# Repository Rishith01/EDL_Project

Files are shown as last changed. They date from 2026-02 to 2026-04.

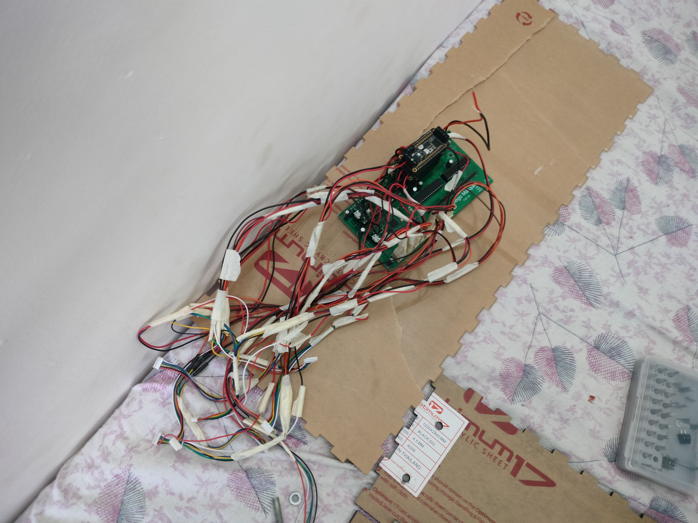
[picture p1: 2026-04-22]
others/extras/images/PCB_wiring.jpg

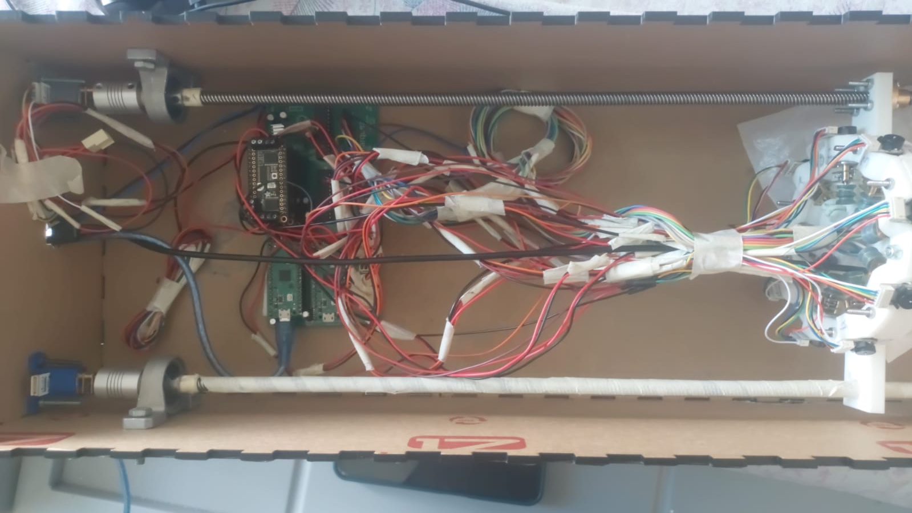
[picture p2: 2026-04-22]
others/images/wiring.jpeg

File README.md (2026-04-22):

<!-- Do Not Change the below line. It will affect your workflow badge -->
Review Assignment Due Date (https://classroom.github.com/a/9lqHKop1)



<!-- ADD YOUR CHANGES AFTER THIS LINE -->

# SACE(Secure Adaptive Continuum Explorer)
**Team TUE-16 | Indian Institute of Technology Bombay**

---

## Team Members
* **Arijit Paul** (23B1219)
* **Arshit Singh** (23B1275)
* **Prithvi Sangam** (23B1292)
* **Rishith Gupta** (23B1234)
* **Veeresh S K** (23B1309)

---

## Project Abstract
This project investigates the practical implementation of **soft robotics** through the development of a modular, tentacle-based end effector on a continuum backbone. The system is engineered to navigate highly constrained environments and perform adaptive grasping of irregular objects. 

The architecture consists of a **continuum robotic arm featuring four flexible segments** capable of extending from a compact enclosure. By integrating 10 degrees of freedom (DOF), tendon-driven actuation, and real-time visual feedback, the robot demonstrates the capability of compliant structures to achieve dexterity and safety in applications where traditional rigid-link manipulators are insufficient.

---

## Key Technical Features
* **Deployable Mechanism:** Engineered for high spatial efficiency, allowing the arm to extend from a compact housing for maximum reach-to-storage ratio.
* **Continuum Kinematics:** A multi-link flexible structure that facilitates smooth, non-discrete bending for complex maneuvering in tight spaces.
* **Adaptive Morphology:** The tentacle-inspired design conforms naturally to the geometry of target objects, ensuring secure grasping through compliant contact.
* **Teleoperated Control:** Real-time operation via a gaming controller/click based interface, mapping user input directly to multi-segment motion.
* **Integrated Vision System:** An endoscope camera provides a live stream to the operator for precise navigation and targeting.
* **Active Safety Array:** Integrated limit switches detect external obstacles and mechanical limits to prevent system damage and ensure safe motion.
* **Modularity:** The system is partitioned into independent subsystems, allowing for streamlined repair, scaling, and iterative refinement.

---

## System Overview

### Hardware Architecture
* **Controller Architecture:** Dual Raspberry Pi Pico microcontrollers configured in a Master–Slave hierarchy to distribute real-time processing loads.
* **Motor Control:** Three Adafruit FeatherWing Motor Drivers, selected for their high-density power management and compact footprint.
* **Actuation:** 11 N20 micro-gear motors dedicated to tendon-driven link manipulation through specialized differential spools.
* **Sensing Array:** 16 Limit Switches (distributed as 4 per continuum segment) for obstacle detection and motion constraint.
* **Vision:** A high-resolution endoscope camera module for front-facing orientation and feedback with 60 degree field of view.
* **Electronics:** A custom-designed PCB for efficient power distribution and signal routing, including 12V to 3.3V power conversion.

### Software Architecture
* **Workstation Logic:** Python-based control scripts on the laptop for signal processing, controller mapping, and user interface management.
* **Embedded Firmware:** MicroPython-based scripts running on the Raspberry Pi Pico for low-level hardware control and motor actuation.
* **Visual Pipeline:** Python-based live feed processing for real-time operator guidance.
The flowcharts and execution logic are present in the folder READMEs. Refer to particular folder for more details.
---

## Working Principle
1.  **Input Acquisition:** The operator provides motion commands through a gaming controller/click and keyboard interface.
2.  **Signal Processing:** The laptop-based Python environment translates given commands into specific link-actuation commands and calculates which link is to move how much using our control algorithm.
3.  **Command Dispatch:** Control signals are transmitted to the Master Raspberry Pi Pico.
4.  **Distributed Execution:** The Master Pico coordinates with the Slave Pico and the motor driver array to execute precise motor rotations.
5.  **Actuation:** N20 motors rotate the differential spools, pulling tendons to induce controlled bending in the continuum segments.
6.  **Feedback Loop:** Real-time visual data from the camera and tactile data from the limit switches are monitored to guide navigation and prevent collisions.

---

## Final Deliverables

The project delivers a fully functional soft robotic system with the following capabilities:

- **Continuum Robotic Arm System**
  - A four-segment tendon-driven continuum arm capable of smooth, multi-directional bending  
  - Designed to navigate constrained environments with high flexibility  

- **Tentacle-Based End Effector**
  - A compliant gripper capable of adaptive grasping of irregular objects  
  - Independently actuated for controlled gripping  

- **Teleoperation Interface**
  - Real-time control using keyboard, mouse, and gaming controller  
  - Supports intuitive interaction through a camera-based interface  

- **Vision-Guided Operation**
  - Integrated endoscope camera providing live visual feedback  
  - Enables precise navigation and targeting  

- **Safety Mechanism**
  - Limit switch array for obstacle detection and motion constraint  
  - Automatic escape responses to prevent system damage  

- **Custom Embedded Control System**
  - Dual Raspberry Pi Pico architecture (Master–Slave)  
  - Distributed control for motor actuation and hardware interfacing  

- **Mechanical and Electronic Integration**
  - Fully assembled system including:
    - Custom PCB  
    - Motor driver integration  
    - Tendon-driven actuation system  

- **User Interface and Control Software**
  - Python-based host system for trajectory planning and control  
  - MicroPython firmware for real-time embedded execution  

---

## Repository Structure

```plaintext
├── src/                # Source code (MicroPython + Python)
├── pcb/                # PCB designs and schematics
│   └── PCB1/
│       ├── design.brd
│       ├── schematic.src
│       └── pictures/   # Fabricated PCB and Fusion 360 layouts
├── 3d_models/          # CAD models (Fusion 360)
│   ├── tentacle/
│   ├── continuum/
│   ├── base_plate/
|   ├── enclosure/
│   ├── spool/
|   └── motor_mount/
├── reports/            # Project Milestone Documentation
│   ├── milestone0/
│   ├── milestone1/
│   ├── milestone2/
|   ├── milestone3/
│   └── milestone4/
├── others/
│   ├── user_manual/    # Operational instructions
│   ├── presentation/   # System demonstration
|       ├── slides/
│       └── video/    
|   ├── images/         # Images of final setup
|   ├── extras/         # Extra images and videos
|   └── diagrams/       # Relevant diagrams
├── bom.xls             # Detailed Bill of Materials
└── README.md
```

## Repository Walkthrough

### src/
Contains all source code for the system, including:
- MicroPython code for the Raspberry Pi Pico, master and slave RPi (motor control, hardware interfacing)
- Python-based host code for user interaction, trajectory planning, and communication  

Each subfolder is organized based on the execution platform and includes relevant README files describing usage and setup.

---

### pcb/
Includes all PCB-related design files and documentation:
- Schematic and layout files for the custom PCB  
- Fabrication outputs and board design files  
- Images of the fabricated PCB and assembled boards  

The PCB integrates motor drivers, power distribution, and control interfaces required for system operation.

---

### 3d_models/
Contains all mechanical CAD designs used in the project.  
The models are organized into subsystem-level folders:
- **tentacle and top_link/** – End-effector for gripping and top link continuum link
- **continuum/** – Flexible links enabling motion  
- **base_plate/** – Structural base and motor mounting  
- **enclosure/** – Outer housing (laser-cut design)  
- **spools/** – Tendon winding mechanisms  
- **Motor Mount/** – Motor holding structures  

Each folder includes design files, images, and descriptions of functionality and assembly.

---

### reports/
Contains all milestone reports documenting the project lifecycle:
- Concept development  
- Design iterations  
- Implementation progress  
- Final system evaluation  

All reports are provided in PDF format.

---

### others/
Contains supporting materials required for understanding and operating the system:
- **user_manual/** – Step-by-step instructions for setup and operation  
- **presentation/** – Slides and demonstration video  
- **images/** – Photographs of the final assembled system  
- **diagrams/** – Wiring diagrams and system-level representations
- **extras/** - Extra images and videos during testing and prototyping

---

### bom.xls
A detailed Bill of Materials listing all components used in the project, including:
- Electronic components  
- Mechanical parts  
- Consumables and fabrication materials  

Each entry includes quantity, description, and source information.

---

### README.md
The root documentation file providing:
- Project overview and objectives  
- System description  
- Repository structure  
- Key features and functionality  
---

## Technical Constraints and Operational Limits
The current design represents a balance between mechanical performance and the physical limitations of the materials and space.

1. **Bending Threshold**: Empirical testing established a stable operational limit of approximately 30° per link. Beyond this angle, mechanical stress increases significantly, contributing to tendon slack issues within the actuation system.

2. **Control Paradigm**: Currently restricted to manual teleoperation; autonomous path planning and inverse kinematics are not yet implemented.

3. **Backbone Hysteresis and Droop**: The use of glue gun sticks as a central backbone introduces stability issues. After bending, the backbone may fail to return to a perfectly linear state, causing the robot to droop. Ensuring the backbone is fixed at the start and end of each link segment is critical for maintaining a consistent neutral axis.

4. **Tendon Dynamics**: Issues regarding tendon slack and potential thread interference in the shared spool design persist during extreme ranges of motion.

---

## Course Reflection and Learnings

### Technical Learnings

This project provided hands-on experience across multiple domains:

- **Mechanical Design**
  - Designing for tolerances and iterative prototyping  
  - Understanding trade-offs between flexibility and structural strength  
  - Challenges in tendon-driven systems such as slack and routing  

- **Embedded Systems**
  - Working with dual microcontroller architecture (Master–Slave)  
  - Interfacing peripherals such as motor drivers, encoders, and port expanders  
  - Handling real-time constraints in MicroPython  

- **Control Systems**
  - Implementing coordinated multi-link motion  
  - Understanding limitations of open-loop control  
  - Practical challenges in achieving smooth motion  

- **PCB Design**
  - Designing and debugging custom PCBs  
  - Managing power distribution and signal routing  
  - Handling hardware failures and component sensitivity  

- **System Integration**
  - Combining mechanical, electrical, and software subsystems  
  - Debugging issues arising only during full system integration  

---

### Team Challenges and Adaptation

- **Subsystem Isolation and Testing**
  - Each subsystem (mechanical, electronics, software) was tested independently before integration  
  - This helped in identifying issues early and reducing debugging complexity  

- **Iterative Prototyping**
  - Multiple iterations were required, especially for:
    - Spool design  
    - Tentacle structure  
    - Continuum links  
  - Rapid prototyping enabled quick validation and refinement  

- **Cross-Domain Collaboration**
  - Team members developed working knowledge of other subsystems  
  - Ensured continuity when specific members were unavailable  

- **Integration Challenges**
  - Most issues arose during integration rather than individual subsystem development  
  - Required coordinated debugging sessions and time alignment among team members  

---

### Honest Reflection

- While the final system achieves the intended functionality, a significant portion of the effort was spent resolving **practical engineering challenges** rather than implementing advanced features  

- Mechanical reliability (tolerances, tendon routing, slack management) proved to be more critical and time-consuming than initially anticipated  

- Hardware failures (motor drivers, microcontrollers) highlighted the importance of robust electrical design and protection  

- The control system works effectively for manual operation, but lacks higher-level intelligence and automation  

- Overall, the project demonstrates a **working proof-of-concept**, but not a fully optimized or production-ready system  

---

### Incomplete Features and Limitations

The following aspects remain incomplete:

- **Autonomous Control**
  - No implementation of inverse kinematics or automated path planning  
  - Reason: Complexity of modeling continuum kinematics and time constraints  

- **Closed-Loop Feedback**
  - Limited use of encoder data for precise control  
  - Reason: Integration complexity and prioritization of basic functionality  

- **Robust Tendon Management**
  - Issues with slack, overlap, and spool behavior at extreme motions  
  - Reason: Mechanical design constraints and limited iteration time  

- **System Stability**
  - Vibrations and minor inaccuracies in motion  
  - Reason: Structural limitations and compact design constraints  

---

### Future Work 

- **Inverse Kinematics for Continuum Arms**
  - Develop simplified models for controlled positioning  

- **Improved Tendon Mechanism**
  - Dedicated spool designs with better separation and tension control  

- **Enhanced Feedback Control**
  - Utilize encoder data for closed-loop control  
  - Implement PID-based corrections  

- **Structural Improvements**
  - Replace glue stick backbone with engineered compliant structures  

- **Miniaturization**
  - Redesign base plate and enclosure for reduced footprint  

- **System Robustness**
  - Add electrical protection (snubbers, proper grounding, shielding)  

---

## Acknowledgements
We extend our sincere gratitude to Prof. Siddharth Tallur, Prof. Himanshu Bahirat, and Prof. P. C. Pandey for their continuous guidance and valuable insights throughout this project. We also acknowledge the support of Ankur, Maheshwar, the WEL RAs and TAs for their technical assistance during the development and debugging phases.

## Inspiration 
The inspiration for the tentacle end effector came from this youtube video of the spirobs bot: https://m.youtube.com/watch?v=Q2yYclPaEV0

Inspiration for the continuum arm came from this video from continnum robotics lab of university of toronto. https://m.youtube.com/watch?v=MxBeUQay8YM

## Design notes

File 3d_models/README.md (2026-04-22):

#  3D Models Overview

This directory contains all mechanical design files used in the Tentacle Arm End Effector project. The designs follow a **modular architecture**, enabling independent development, testing, and iteration of each subsystem.

---

##  Design Philosophy
- **Modularity** – Each subsystem (tentacle, continuum links, base, etc.) is designed independently for ease of iteration and replacement  
- **Tendon-driven actuation** – Motion is achieved through routed tendons enabling flexible bending  
- **Iterative prototyping** – Multiple versions were developed to resolve tolerance, routing, and mechanical constraints  
- **Ease of fabrication** – Designs are optimized for rapid prototyping using accessible manufacturing methods  

---

##  Manufacturing Methods
- **3D Printing ** – Used for all structural components (STL files)
- **Laser Cutting** – Used for enclosure panels (DXF files)  

---

##  Materials Used
- **PLA (Primary Material)**  
  - Chosen for its balance between rigidity, printability, and cost  
  - Provides sufficient structural strength while allowing minor compliance  

- **TPU (Tested)**  
  - Too flexible for structural components  

- **Resin (Tested)**  
  - High precision but expensive and limited in build volume  

- **Acrylic (6mm)**  
  - Used for enclosure panels via laser cutting  

---

##  Design Considerations
- **Tolerance management** was critical across all components  
- Minor post-processing (filing/drilling) was required in tight-fit regions  
- **Tendon routing** and **vinyl tubing guidance** were key constraints  
- Structural strength balanced with flexibility for continuum motion  

---

##  System Integration
The mechanical assembly follows this structure:
entacle → Continuum Links (×4) → Base Plate → Lead Screw → Enclosure

- The **tentacle** performs grasping  
- The **continuum links** enable flexible motion  
- The **base plate** houses motors and routing  
- The **lead screw** enables linear extension  
- The **enclosure** houses the entire system  

---

## Folder Structure
```plaintext
.
├── enclosure/     # Laser-cut enclosure designs (DXF)
├── base_plate/    # Base plate designs and iterations
├── spools/        # Tendon winding mechanisms
├── continuum/     # Continuum link structures
└── tentacle/      # Gripper/tentacle designs
```

Each folder contains design files along with images and detailed README documentation.

## Assembly Instructions

The assembly of the Tentacle Arm End Effector is carried out in stages, starting from the continuum structure to the final enclosure integration.

---

### 1. Continuum Link Assembly

- Attach the continuum link segments along a central **hot glue stick backbone**, maintaining uniform spacing  
- For each link:
  - Tie **four fishing lines** at 90° intervals around the link  
  - Ensure consistent positioning for symmetric actuation  

---

### 2. Tendon Routing

- Route each fishing line through the **vinyl tubing guides**  
- This ensures:
  - Reduced friction  
  - Controlled motion  
  - Proper alignment between links  

- Repeat this process for all continuum links and route all tendons down to the base plate  

---

### 3. Base Plate and Motor Assembly

- Mount all motors securely onto the **base plate** using appropriate screws  
- Route the fishing lines through designated holes in the base plate  
- Wind each tendon onto its respective **spool mechanism**  
- Attach the spools firmly onto the **motor D-shafts**

---

### 4. Lead Screw Integration

- Connect the **base plate** to the lead screw mechanism  
- Attach the lead screw to the motor using a **shaft coupler**  
- Mount the lead screw motor onto the **motor mount**

---

### 5. Enclosure Integration

- Fix the motor mount and lead screw assembly inside the **enclosure**  
- Ensure alignment of the continuum structure with the enclosure exit opening  

- For additional stability:
  - Support the lead screw using **pillow bearings**  
  - Secure them to the enclosure structure  

---

### 6. Final Checks

- Verify all tendons are properly tensioned  
- Ensure smooth rotation of motors and spools  
- Check for:
  - No tendon overlap  
  - No obstruction in tubing  
  - Free movement of continuum links 
- Can check for each motor's working and mechanical issues by running individual commands on Thonny for each motor. 

---

### Notes

- Minor adjustments (tightening, re-routing, or trimming) may be required due to tolerance variations  
- Proper tendon tension is critical for accurate motion and control

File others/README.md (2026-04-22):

# Others Directory

This directory contains all supplementary materials related to the **SACE (Secure Adaptive Continuum Explorer)** project. It complements the core implementation by providing user documentation, system visuals, demonstrations, and additional validation data.

---

## Purpose

The `/others` folder is intended to:
- Provide a complete **user-facing understanding** of the system  
- Document the **final assembled setup** visually  
- Showcase **demonstration and testing results**  
- Include **supporting diagrams and development artifacts**  

---

## Folder Structure

```plaintext
others/
├── user_manual/
├── presentation/
│   ├── slides/
│   └── video/
├── images/
├── diagrams/
└── extras/
```

## Subfolder Descriptions
🔹 user_manual/

This folder contains the User Manual for the SACE system.

It includes:
```
System setup instructions
Step-by-step operating procedures
Safety guidelines
Troubleshooting information
```
This document is intended for end-users interacting with the system.

🔹 presentation/

This folder contains materials used for project demonstration and evaluation.
```
slides/: Final presentation slides (PDF format)
video/: Demonstration videos showcasing system operation, capabilities, and performance
```
🔹 images/

This folder contains images of the final assembled system, including:
```
Overall system setup
Mechanical structure
Electronics and wiring
Enclosure and integration
```
These images serve as visual proof of system completion.

🔹 diagrams/

This folder includes technical diagrams that describe the system design and operation:
```
Hardware interconnection diagrams
```
These help in understanding how different subsystems interact.

🔹 extras/

This folder contains supplementary material from the development and testing phases.
```
images/: Photos from prototyping, intermediate builds, and debugging stages
videos/: Testing videos demonstrating subsystem behavior and iterative improvements
```
This section highlights the evolution of the system and provides additional validation of design decisions.

## Notes
All content is organized for clarity and ease of navigation
File names are chosen to be descriptive and self-explanatory
This directory supports and enhances the documentation in /src, /pcb, and /3d_models
## Summary

The /others directory provides a comprehensive collection of documentation, visuals, and demonstrations that enhance the usability, understanding, and presentation of the SACE system.

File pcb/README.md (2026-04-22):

# PCB information and Post-Fabrication Modifications

This PCB was designed using **Autodesk Fusion 360 (Fusion Electronics)**. It consists of 2 RPIs(both communicate over I2C, one is connected to the laptop[master] and the other is the slave). Slave RPI collects encoder information and relays it to the main RPI. We did this because we were worried about the computing capability of a single RPI. The master RPI also controls 2 GPIO port expanders[MCP23S17](over SPI), which provide a means to get feedback using the limit switches. This RPI also controls the Adafruit Featherwing motor drivers(via I2C), 3 of the drivers are stacked on top of each other using stackable header pins. It also contains an AMS1117 3.3V LDO to power the logic using a 12V input. More information about the schematic is available in the image below.



Following fabrication, a few manual trace modifications (often referred to as "micro-surgeries" or bodge wires) are required on the physical board to correct an inconsistency with the SPI bus routing.

## Layout issue
### SPI issue
In the initial PCB design, the pin assignments for the **MCP23S17** (specifically the one closest to the Raspberry Pi) were mistakenly split across two different SPI buses. The original, incorrect routing was as follows:

* **`GP6`** (Pin 9, SPI0 SCK) -> MCP23S17 SPI SCK
* **`GP7`** (Pin 10, SPI0 TX) -> MCP23S17 SPI TX
* **`GP8`** (Pin 11, SPI1 RX) -> MCP23S17 SPI RX
* **`GP9`** (Pin 12, SPI0 CS) -> MCP23S17 SPI CS

### RPI VBUS issue
Main RPI's VSYS pin(Pin 39) was connected to the 3.3V power rail on the PCB. The issue was that the main RPI had to be connected to the laptop via a USB cable while operating the robot which caused the VSYS pin to output 5V as it was connected to the power line of the USB. This forced the bus to go to 5V and fried our LDO(AMS 1117).

## Fixes 
### Microsurgery
To maintain SPI consistency and ensure the interface operates on a unified bus, the SPI TX and SCK lines for this MCP23S17 must be manually reassigned. The following corrections were made on the fabricated board:

* **MCP23S17 SPI TX** (Pin 8) -> Reroute to **`GP14`** (Pin 19)
* **MCP23S17 SPI SCK** (Pin 9) -> Reroute to **`GP15`** (Pin 20)
  
### Cutting pin headers 
Originally, the 3.3V bus going towards the main RPI was cut, but then we realised that it provided power to the slave RPI and encoders down the line, so we had to solder the cut trace and cut the pin headers for VSYS and VBUS of the main RPI using flush cutters so that 5V and 3.3V are not shorted.

Here is the pico pinout for easy reference.

pico-pinout

## Purpose of PCB
- Wiring Mangement
- Keeping the electronics in one compartment
- Connecting all power sources needed to one main power port
- Fixing Wire ends for N20 motor connectors ( There were too many motors, needed a way to sort and compile all motor connections )

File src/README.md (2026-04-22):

# Continuum Robot Control System

## Overview
A distributed control system for a tendon-driven continuum robot:
- **Laptop (Host)**: planning, UI, safety decisions
- **Master Pico**: real-time control, safety arbitration
- **Slave Pico**: high-speed encoder processing

---

## System Architecture
```mermaid
flowchart LR
    %% ===== USER & HOST =====
    U[User] --> H[Laptop Host]

    %% ===== COMMAND PATH =====
    H -->|USB Serial Commands| M[Master Pico]

    %% ===== ACTUATION PATH =====
    M -->|I2C Control| D[PCA9685 Drivers]
    D -->|PWM Signals| MOT[DC Motors]

    %% ===== FEEDBACK LOOP =====
    MOT -->|Quadrature Signals| ENC[Encoders]
    ENC -->|GPIO| S[Slave Pico]
    S -->|I2C Telemetry| M

    %% ===== LIMIT SAFETY LOOP =====
    LS[Limit Switches] -->|Digital Signals| MCP[MCP23S17 Port Expanders]
    MCP -->|SPI| M

    %% ===== STATUS BACK TO HOST =====
    M -->|LIMIT / TIMEOUT Events| H
```

---

## Data Flow
```mermaid
sequenceDiagram
    participant U as User
    participant H as Laptop
    participant M as Master
    participant S as Slave

    U->>H: Input (click/keys)
    H->>M: START / GRIP
    M->>S: Reset encoder
    S-->>M: Encoder ticks
    M-->>H: LIMIT / TIMEOUT
```

---

## Project Structure
```
/Project-Root
├── src/
│   ├── Python_VSCode/
│   │   └── Teleop/
│   └── Micropython_Thonny/
│       ├── Master_RPi/
│       └── Slave_RPi/
```
## Step-by-step Execution Flow
- Load master code and Slave code to 2 different Rasberry Picos.
- Make the connections as given in the pcb section ( refer to the schematic and the guideline in PCB README.md ).
- Connect main Rasberry Pico to Laptop and run the main.py on master RPI.
- Run the code ( see the COM port connections for USB and Endoscope Camera ).
- Done! Now see Teleop README.md to find the commands.

## Platform and Specifications
- Thonny used for flashing code on Rasberry Pico
- Micropython used for master and slave RPi code ( Version MicroPython v1.25.0 )
- Python3 used for code for Teleop
- Communication protocols used : SPI , I2C and USB Serial ( UART over USB )

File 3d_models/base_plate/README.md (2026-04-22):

#  Base Plate Design

##  Purpose
The base plate acts as the **foundation of the robot**, supporting:
- Motors  
- Tendon routing  
- Limit switch integration  
- Connection to the lead screw  

---

##  Iterations
### Version 1
- Motors mounted externally  
- Limited routing provisions  

### Version 2 (Final)
- Motors integrated directly onto the base plate  
- Increased dimensions to accommodate components  
- Additional holes for:
  - Limit switches  
  - Vinyl tube routing  
  - Structural mounting  

---

##  Design Features
- Motor mounting holes aligned to specifications  
- Routing paths for tendons and vinyl tubes  
- Interface for lead screw connection  
- Structural support for entire robot assembly  

---

##  Challenges
- Tolerance issues required iterative redesign  
- Minor post-processing (filing/drilling) used for fitting  

---

##  Notes
All iterations are included for reference along with corresponding images.

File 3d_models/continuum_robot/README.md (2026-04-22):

# Continuum Link Design and Development

## Purpose
Continuum links serve as the primary structural and functional units of the robot, designed to provide **flexible, multi-directional motion**. Unlike traditional rigid-body joints, these links allow the robot to achieve smooth curvature, enabling it to navigate through highly constrained or irregular environments.

---

## Technical Structure and Components
Each link is a precision-engineered manifold designed to manage structural support, sensing, and actuation routing. 
* **Actuation Channels:** Four dedicated tendon pathways arranged at 90-degree intervals.
* **Spring Mounting Interface:** Four mounting points for springs that provide the restorative force necessary to return the link to a neutral position.
* **Obstacle Avoidance System:** Four limit switches are integrated at 90-degree intervals, positioned strategically between the springs and the tendons to detect external contact.
* **Internal Manifolds:** Specialized internal paths are provided specifically for the routing of limit switch wiring to ensure it does not interfere with moving parts.
* **Vinyl Tubing Guides:** Vertical guides house vinyl tubing, which is critical for independent link control. By fixing the relative motion of the link below, the tubing ensures that a tendon passing through it can directly actuate the current link without being affected by the movement of previous segments.

---

## Working Principle
The links operate on a tendon-driven continuum mechanics principle:
* **Antagonistic Pairs:** Tendons are arranged in opposing pairs; pulling one side creates a compressive force that results in a controlled bend in that direction.
* **Individual Link Control:** The use of tubing allows the system to isolate forces, enabling the differential actuation of specific links to achieve complex shapes rather than a simple uniform curve.
* **Central Backbone:** A central core (utilizing a glue-stick material) provides high compressive strength to withstand tendon tension while maintaining the lateral flexibility required for bending.

---

## Iterative Refinement
The design progressed through approximately three major iterations, focusing on structural durability and routing efficiency:
* **Structural Reinforcement:** Early versions suffered from mechanical failure where the pulling force on the vinyl tubing caused the link structure to break. Later iterations improved the housing geometry to better distribute these localized stresses.
* **Pathing Integrity:** Internal routing was refined to accommodate the limit switch wiring and tendons simultaneously without entanglement or signal interference.
* **Anchor Point Optimization:** The holes for tendon anchoring were adjusted to ensure they could withstand the high tension required for maximum deflection.

---

## Current Constraints and Design Considerations
While the current link configuration is highly functional, specific mechanical trade-offs were identified:

* **Backbone Hysteresis and Droop:** The use of glue gun sticks as a central backbone introduces significant stability issues. After bending, the backbone often fails to return to a perfectly linear state. This residual bending results in twists within the gaps between links, causing the robot to "droop" toward one side in its relaxed position. To maintain a consistent neutral axis, it is necessary to fix the backbone position at specific intermediate points—specifically at the start and end of each link segment.

* **Spring-Based Support:** The current use of springs for support provides the required restorative force and allows for bending, but it was primarily implemented as a baseline support mechanism. A more specialized structural alternative could potentially offer better uniform resistance and stability.

---

This design represents a robust solution for independent link control and 360-degree obstacle detection within the 30-degree limit. Future developments may explore more rigid intermediate backbone constraints or alternative support structures to achieve even greater curvature and stability.

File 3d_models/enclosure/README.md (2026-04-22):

# Enclosure Design

## Purpose
The enclosure serves as the **outer housing** of the system, providing structural support and protection for internal components. It also guides the robot through a constrained exit point.

---

## Manufacturing
- **Material**: 6mm Acrylic  
- **Process**: Laser cutting  
- **File Format**: DXF  

---

## Design Features
- Panel-based design for easy assembly  
- Central opening for robot deployment  
- Slots and edges designed for alignment  
- Internal space for housing electronics and structure  

---

## Assembly
- Panels are assembled using **interlocking wedge-based joints**  
- Additional **tape reinforcement** is used for structural safety  
- Screws used where necessary for mounting

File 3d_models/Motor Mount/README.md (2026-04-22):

## Motor mound

- Was 3D printed by us
- Used for attaching the lead screw motor to the back plate of the box enclosure

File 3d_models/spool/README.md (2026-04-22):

# Spool Design and Development

## Purpose
The spool assembly is the primary mechanical interface responsible for **tendon actuation**. It converts the rotational motion of the motors into controlled linear displacement, which pulls the tendons to actuate the continuum robotic links.

### Operational Logic
* **Dual-Tendon Control:** Each individual spool manages two tendons.
* **Differential Winding:** The spool utilizes a differential winding configuration. As the motor rotates, one tendon is wound (pulled) while the opposing tendon is unwound (released), enabling precise bidirectional control of the robot's bending.

---

## Iterative Development Process
The spool underwent approximately five iterations to move from a basic cylinder to a specialized mechanical component. This evolution was driven by the need to solve common failures in tendon-driven systems.

### Initial Design Failures
The earliest prototypes lacked internal constraints, leading to several issues:
* **Tendon Overlap:** Without dedicated paths, tendons would wind over themselves, changing the effective radius of the spool and causing inconsistent actuation.
* **Tendon Tangling:** The absence of separators allowed opposing tendons to interfere with each other, leading to mechanical jams.

### Design Refinements
To resolve these failures, the following features were integrated into subsequent iterations:
* **Wedge-Based Separators:** Internal dividers were added to create independent channels for each tendon, ensuring zero interference.
* **Tilted Routing Paths:** Angled internal geometry guides the tendon naturally during the winding process, preventing the thread from stacking on itself.
* **Chamfered Edges:** All contact surfaces are chamfered to reduce friction and minimize abrasive wear on the tendons during high-tension cycles.
* **Shaft-Compatible Mounting:** The core is designed with a "D-profile" to match the motor shaft, ensuring direct torque transfer.

---

## Technical Challenges and Constraints

The current design represents a balance between mechanical performance and the physical limitations of the materials and space.

### 1. Mechanical Limits and Slack Formation
A persistent challenge is the formation of tendon slack during extreme motion. Empirical testing reveals that when the continuum link is actuated beyond a **30-degree bending angle**, the mechanical limit of the link is reached. At this threshold, the tendon displacement ratio becomes non-linear, causing the opposing tendon to lose tension and develop slack.

### 2. Geometry Trade-offs
There is a direct trade-off regarding the height of the internal separators:
* **Separation vs. Size:** While taller separators provide better tendon isolation, they increase the overall spool height.
* **Cascading Footprint:** A taller spool necessitates a larger **base plate** and a taller **protective cap**. To maintain a compact robotic base, the separator height must be kept at a functional minimum.

### 3. D-Shaft Wear and Friction
Under high-torque conditions, the interface between the motor and the spool is a point of failure:
* **Material Fatigue:** Friction and high pressure cause the "D" shaped profile of the motor shaft to gradually wear down the internal profile of the spool.
* **Torque Slippage:** As this profile rounds off, it leads to backlash or total slippage, where the motor shaft rotates but fails to turn the spool effectively.

---
While this design represents the most effective solution developed within our current constraints, it is not necessarily the absolute optimal configuration, and future iterations may explore new geometries to facilitate greater bending angles.

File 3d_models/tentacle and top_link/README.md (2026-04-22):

#  Tentacle Design

##  Purpose
The tentacle functions as the **end-effector**, designed specifically for **soft gripping of objects**.

---

##  Material
- **PLA (Final choice)**  
- Selected for structural stability and manufacturability  

---

##  Iterations
5–6 design iterations were developed, exploring:
- Material choices (PLA, TPU, Resin)  
- Number of segments  
- Interlocking/locking mechanisms  
- Tolerances and fit  

---

##  Actuation
- Operates using a **separate tendon system**  
- Independently controlled from continuum links  

---

## 🧩 Design Features
- Modular segmented structure  
- Interlocking joints for controlled bending  
- Designed for adaptive gripping  

---

## 📈 Performance
- Achieves reliable gripping for moderately sized objects  
- Demonstrates adaptive contact due to compliant structure  

---

## ⚠️ Challenges
- Tolerance sensitivity between segments  
- Trade-off between flexibility and strength  

---

## 📷 Notes
All design versions and final assembly images are included.

## Files
- .stl are the CAD files.
- .png and .jpeg are images.
- Tentacle.stl is the tentacle.
- tentacle_link.stl is the continuum link on which the tentacle is placed.

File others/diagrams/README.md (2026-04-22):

🔹 diagrams/

This folder includes technical diagrams that describe the system design and operation:
```
Hardware interconnection diagrams

PCB wiring diagram
```
These help in understanding how different subsystems interact.

# Wiring and Electrical Connections

## Overview

The wiring of the system primarily consists of:
- Power distribution (12V and ground)
- Motor and encoder connections
- Limit switch interfacing
- Communication between modules (PCB, Raspberry Pi Pico, motor drivers)

The design emphasizes modularity, ease of debugging, and safe operation.

---

## Power Distribution

- A **12V SMPS** is used as the main power source  
- Power is supplied to the PCB through **screw terminals**

### Wiring Convention
- **Red** → +12V (VCC)  
- **Black** → Ground (GND)  
- Other colors → Signal lines (motors, encoders, limit switches)

### Notes
- Ensure tight screw terminal connections to avoid voltage drops  
- Ground is shared across all modules (common ground reference)

---

## Motor and Encoder Connections

- N20 motors are connected to the PCB via **motor driver outputs (Adafruit FeatherWing)**  
- Each motor is paired with an **encoder**, which relays feedback to the **Slave Raspberry Pi Pico**

### Mapping
- Motors are indexed from **0 to 10**
- Direction control:
  - Achieved in software  
  - Can be reversed by swapping motor polarity if required  

### Encoder Interface
- Encoder signals are routed to the **Slave Pico**
- Used for:
  - Motion tracking  
  - Basic feedback  

---

## Limit Switch Connections

- A total of ~16 limit switches are used  
- Distributed across continuum links for collision detection and motion limits  

### Electrical Configuration
- Each switch is connected as a **digital input**
- Typical wiring:
  - One terminal → GND  
  - Other terminal → GPIO (via port expander)  

- Operates in **pull-up configuration**:
  - Default state → HIGH  
  - Triggered (pressed) → LOW  

---

## Port Expander Interface

- Limit switches are connected via **GPIO port expanders (MCP23S17 over SPI)**

### Function
- Expands available input pins  
- Reduces load on the Raspberry Pi Pico  

### Mapping
- Mapping of:
  - Expander ID (`mcp_id`)
  - Pin number  

is handled in software and can be modified without hardware changes  

---

## Motor Driver Connections

- **Adafruit FeatherWing motor drivers** are used for motor control  
- Controlled via I2C from the Master Pico  

### Features
- Compact integration of multiple motor channels  
- Simplifies wiring and reduces PCB complexity  

---

## Connector Types

The system uses the following connectors:

- **Screw Terminals**
  - For power input (12V, GND)
  - Provides secure and reliable connections  

- **Pin Headers / JST Connectors (as applicable)**
  - For:
    - Motor connections  
    - Encoder signals  
    - Limit switches  

- **Motor Leads**
  - Pre-attached wires from motors used for:
    - Motor power  
    - Encoder output  

---

## Intermodule Connections

### 1. Laptop ↔ Master Pico
- USB Serial communication  
- Used for command transmission and feedback  

---

### 2. Master Pico ↔ Motor Drivers
- I2C communication  
- Controls motor speed and direction  

---

### 3. Master Pico ↔ Port Expanders
- SPI communication  
- Reads limit switch states  

---

### 4. Slave Pico ↔ Encoders
- Direct GPIO connections  
- Handles encoder signal processing  

---

### 5. PCB ↔ Mechanical System
- Motors mounted on base plate  
- Wiring routed through structured paths to avoid interference  

---

## Design Considerations

- Modular wiring enables easy debugging and replacement  
- Color-coded wiring improves readability and maintenance  
- Separation of power and signal lines reduces noise  
- Port expanders simplify large-scale input handling  

---

## Notes

- Ensure all grounds are common across modules  
- Use masking tape to avoid shorting as done in our figures
- Check polarity before powering the system  
- Loose wiring may result in:
  - False limit switch triggers  
  - Unstable motor behavior  

- All connections should be verified before operation for safe functioning of the system
=======

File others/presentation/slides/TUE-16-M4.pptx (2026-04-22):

## TUE-16

Secure Adaptive Continuum Explorer

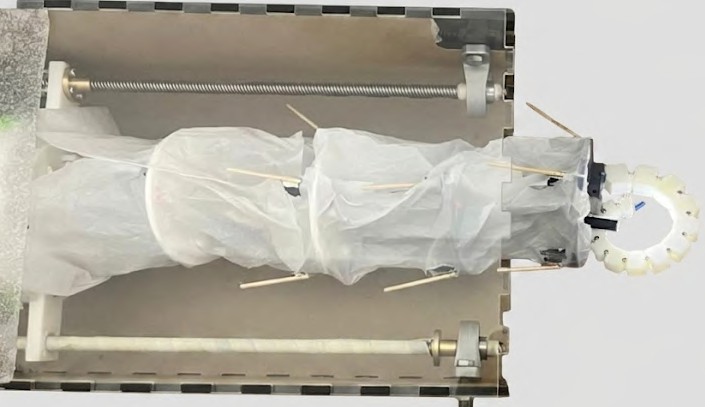
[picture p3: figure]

VEERESH S K (23B1309) RISHITH GUPTA (23B1234) ARSHIT SINGH (23B1275) PRITHVI SANGAM (23B1292) ARIJIT PAUL (23B1219)

## SUMMARY

- modular continuum tentacle-based end-effector using tendon-driven actuation and visual feedback
- industrial maintenance, medical/surgical researchers and rescue professionals requiring flexible robotic systems
- overcomes limited accessibility and dexterity, adaptive grasping and safe interaction

01
02
03

WHAT?

WHO?

PROBLEM?

## SPECIFICATIONS

01 LINK BENDING : 30°

04
05

MINIMUM GRABBING : 1.25 cm RADIUS

02

EXTENSION OF : 40 cm LEADSCREW

MAXIMUM GRABBING : 3.5 cm RADIUS

03 CAMERA FOV : 60°

## STATUS OF PROJECT

Key Requirements proposed at the beginning of the semester

bending of individual continuum links

Status at end of semester

complete

Remarks/Justification

end-effector object gripping

hybrid continuum-tentacle mechanical design

complete

complete

## STATUS OF PROJECT

Key Requirements proposed at the beginning of the semester

user control through GUI commands on keyboard with live camera feedback

limit switch-based obstacle avoidance

Status at end of semester

complete

complete

Remarks/Justification

## STATUS OF PROJECT

Key Requirements proposed at the beginning of the semester

Status at end of semester

Remarks/Justification

manual control algorithm complex, and more costly sensors required

integrated multiple RPis and ICs

autonomous navigation, control and object retireval

complete

incomplete

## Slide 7

PHOTOGRAPHS OF FINAL PROTOTYPE

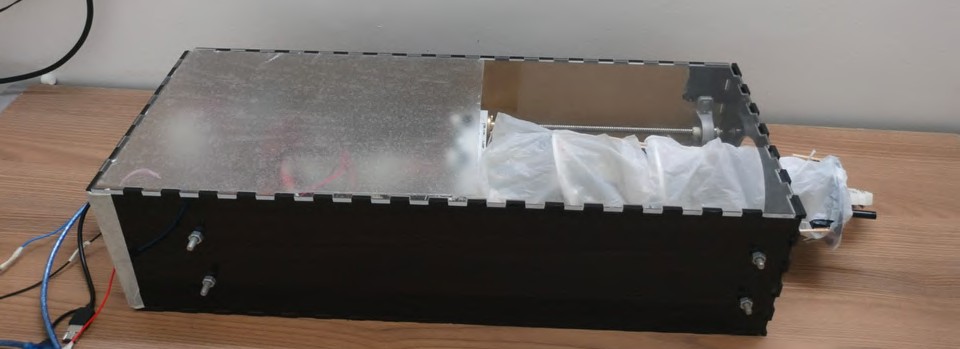
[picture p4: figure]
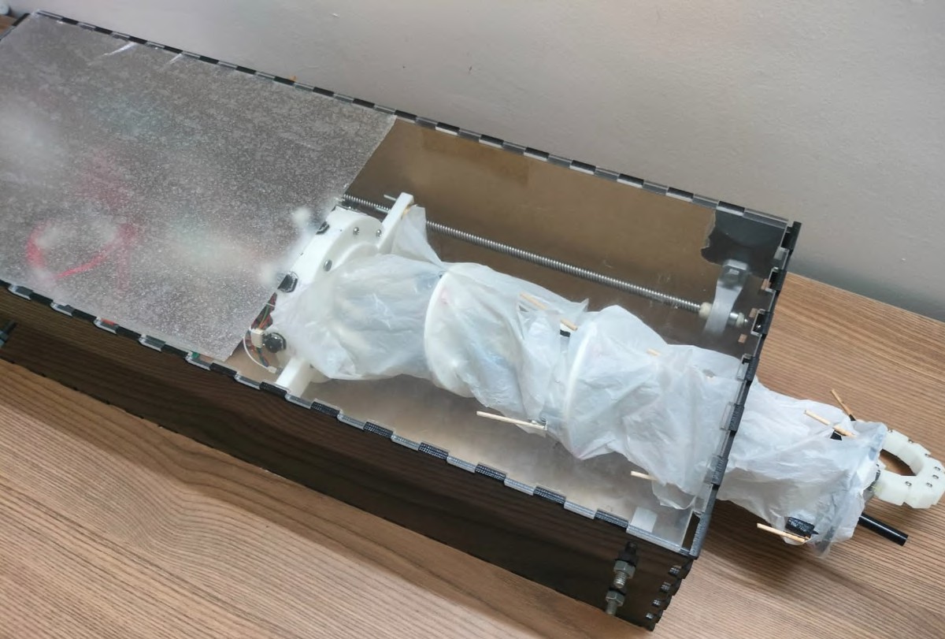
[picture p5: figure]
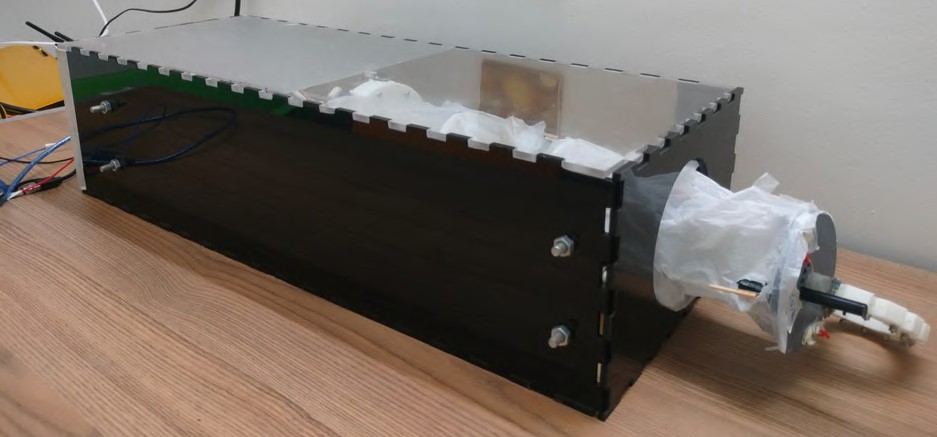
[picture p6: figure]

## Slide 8

PILLOW

BEARING

LEADSCREW

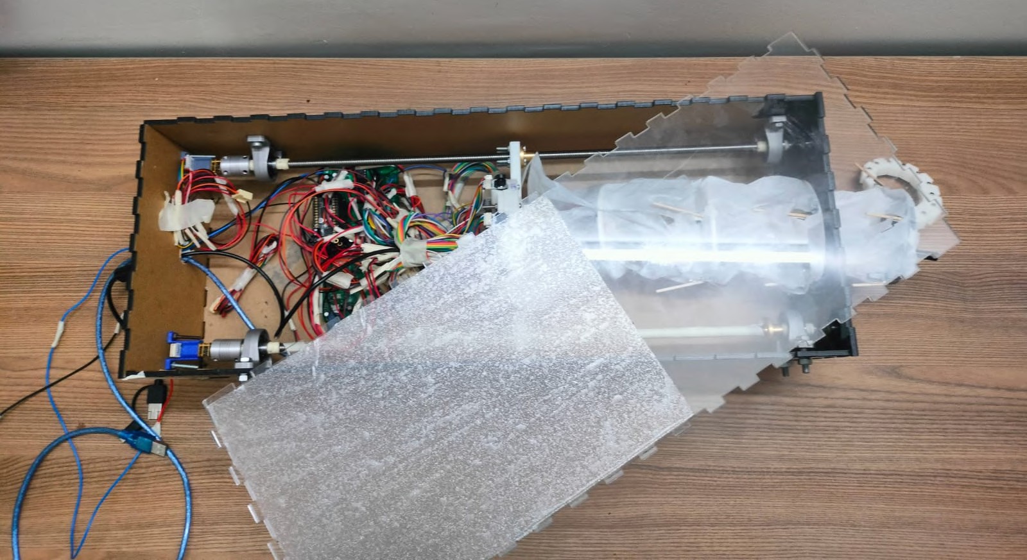
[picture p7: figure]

CONTINUUM LINKS

ENTDE-NEFTAEF CCLTEOR

COUPLERS

PCB

## MOTOR DRIVER

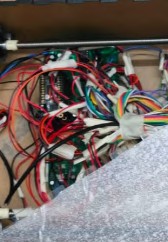
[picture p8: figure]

ENDOSCOPE

CAMERA

BASE PLATE WITH MOTORS

LEADSCREW

MASTER RPI

LIMIT SWITCHES

MOTOR

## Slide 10

CONTINUUM BENDING TO THE LIMIT !!!

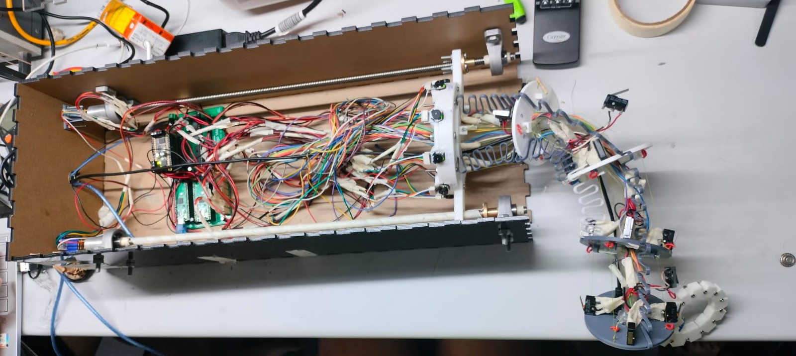
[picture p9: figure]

## Challenges

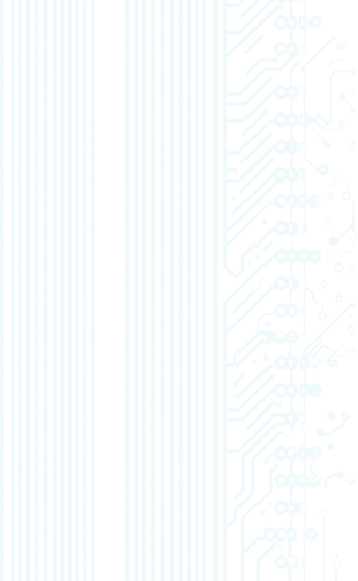
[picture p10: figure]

spool design

tentacle material choice and design

Solutions

Remarks

multiple iterations, 2 winding spool with opposite directions

final design hinge-based, printed in PLA, tried resin printing

working but better solutions possible

effective bending and movement

CHALLENGES

FACED AND

HOW WE

SOLVED

THEM

insufficient ports on RPi Pico

used port expanders and master-slave architecture

increased ports (26 to 26+32) and better task distribution

realised torque was less

changed routing of cables and brought motors to base plate

getting enough torque

## Challenges

mistakes in PCB design

defect in motors

Solutions

fixed using micro-surgery and removal of Vsys of main RPi

Remarks

PCB is working without any issues

CHALLENGES

FACED AND

HOW WE

SOLVED

THEM

micro-surgery to connect terminals and connector

motor defect fixed and working

double lead screw alignment

keeping one lead screw stationary, moving other

better movement than earlier

tight mechanical tolerances

changed designs and 3D printers for better prototype

more flexible and accurate design

## DEMO VIDEO

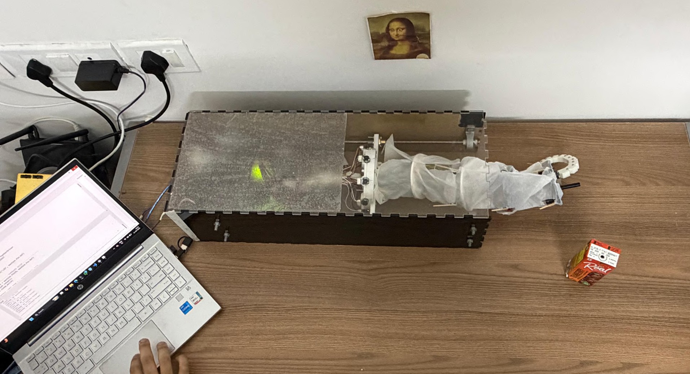
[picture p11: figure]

## MINDS BEHIND THIS

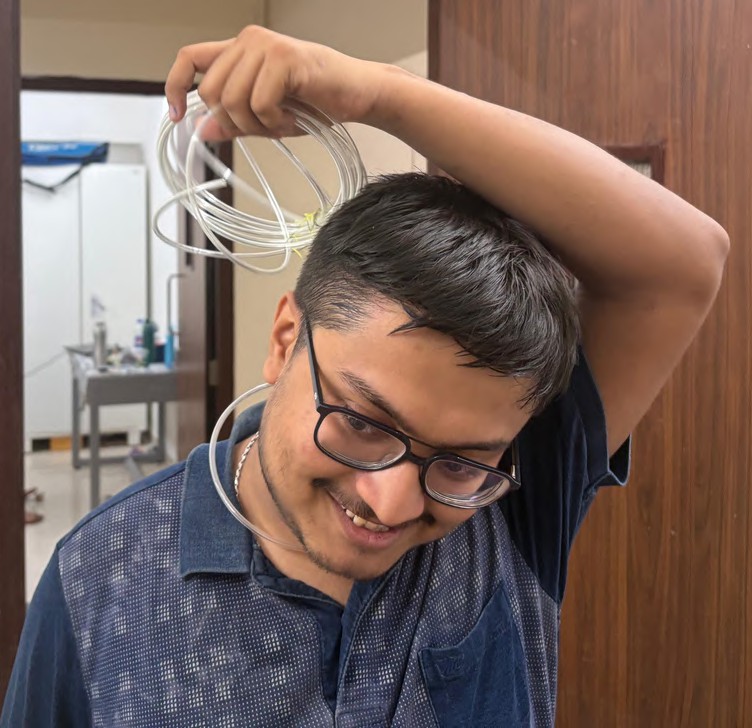
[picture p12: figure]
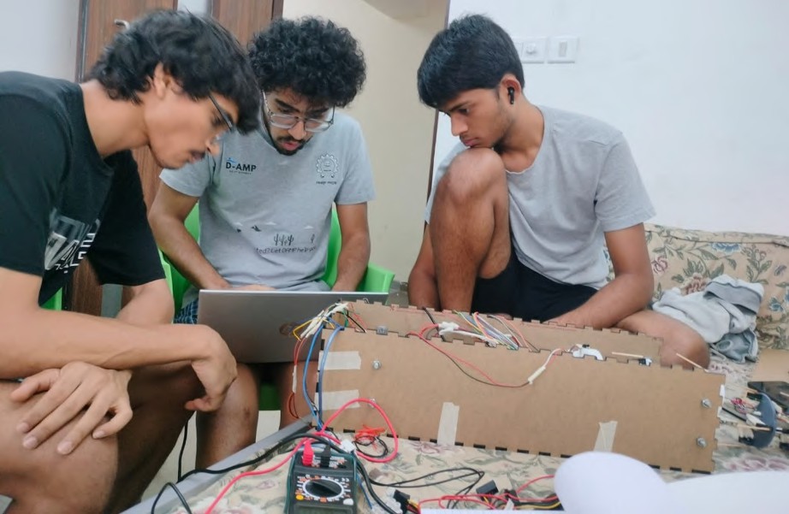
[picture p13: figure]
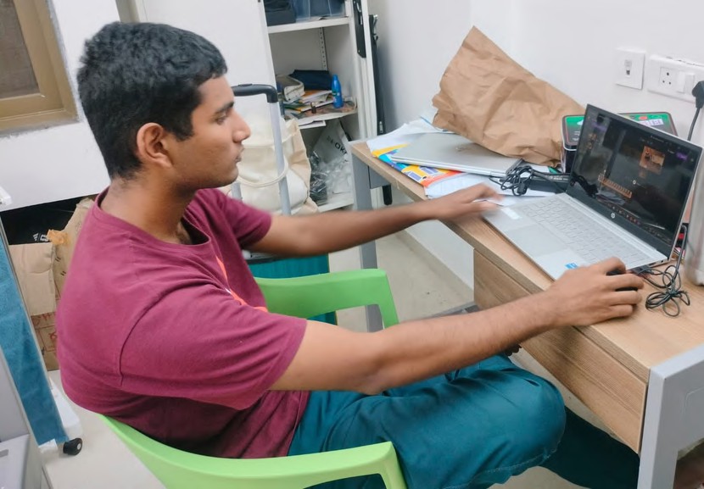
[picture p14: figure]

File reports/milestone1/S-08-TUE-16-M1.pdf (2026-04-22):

# Hybrid Continuum-Tentacle Robotic Manipulator

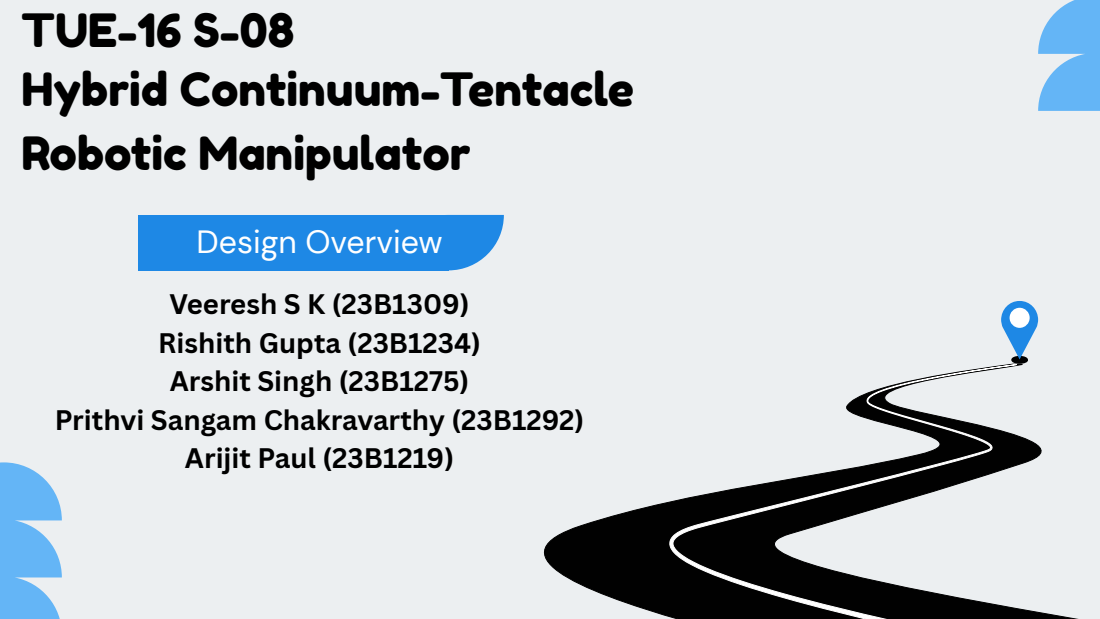
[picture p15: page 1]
Design Overview; Veeresh S K (23B1309) Rishith Gupta (23B1234) Arshit Singh (23B1275); Arijit Paul (23B1219); TUE-16 S-08

Prithvi Sangam Chakravarthy (23B1292)

# PROBLEM STATEMENT

1

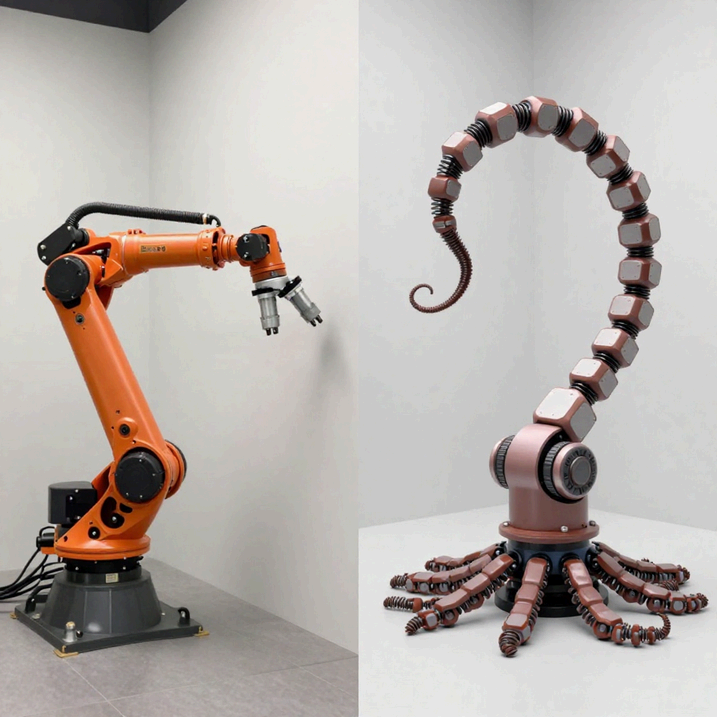
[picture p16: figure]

### Spatial Inflexibility: Fixed-link systems are geometrically "locked"; they cannot deform their

own structure to pass through small apertures.

### High Effective Mass: Rigid joints require heavy motors at each link, leading to high inertia that

makes soft touches hard.

# The "Rigidity Gap"

# The "Rigidity Gap"

### Kinematic Dead Zones: Standard 6-DOF arms

### often encounter "singularities" or blind spots where they cannot orient the gripper without a

wide, sweeping reset movement.

### Environmental Fragility: Because they cannot

### absorb impact, rigid robots are easily damaged by (and cause damage to) unpredictable

surroundings like debris or organic tissue.

# PROPOSED SOLUTION VALUE PROPOSITION

2

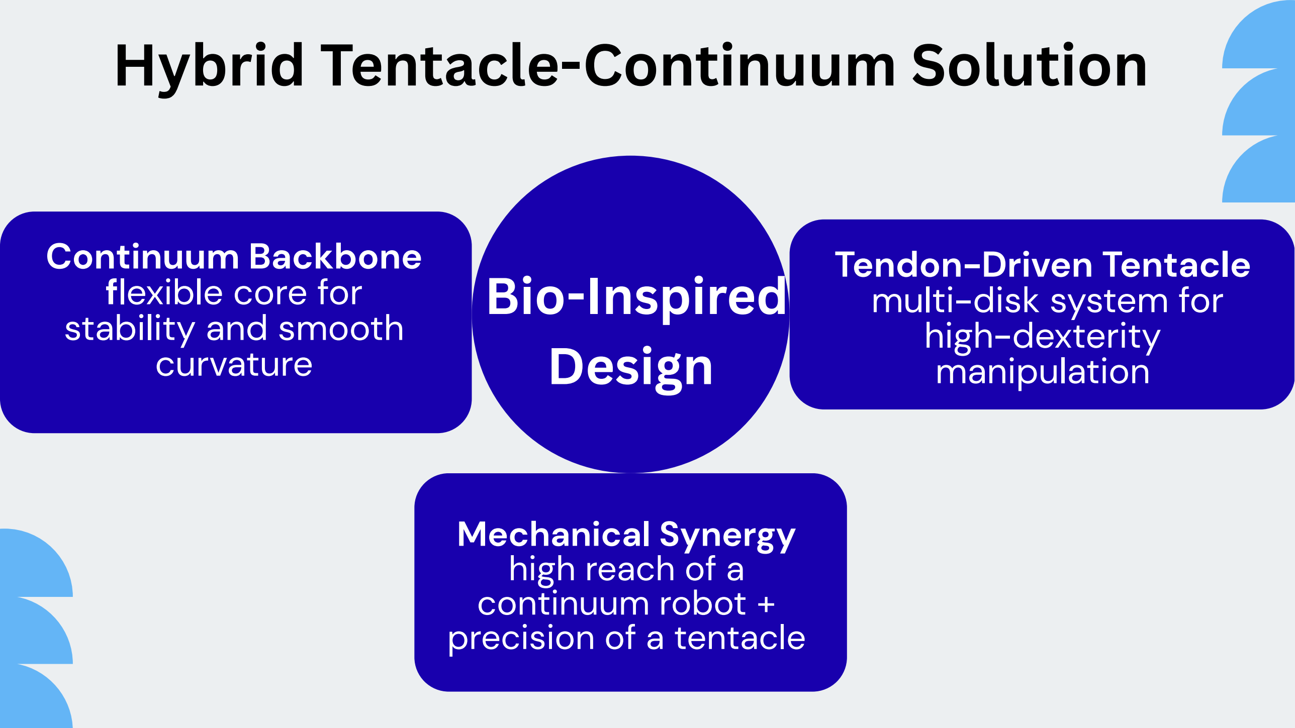
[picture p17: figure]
Hybrid Tentacle-Continuum Solution; Bio-Inspired Design; Continuum Backbone flexible core for stability and smooth curvature; Tendon-Driven Tentacle multi-disk system for high-dexterity manipulation; Mechanical Synergy high reach of a continuum robot + precision of a tentacle

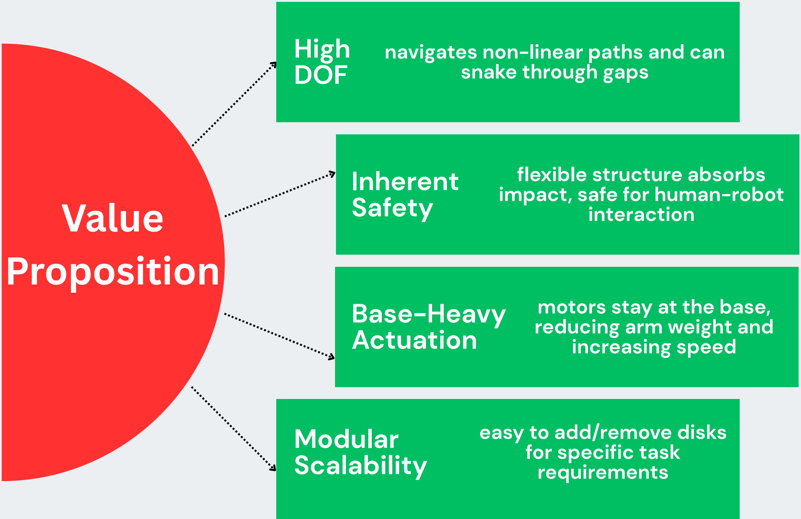
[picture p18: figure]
Value Proposition; High DOF; Inherent Safety; Base-Heavy Actuation; Modular Scalability; navigates non-linear paths and can snake through gaps; flexible structure absorbs impact, safe for human-robot interaction; motors stay at the base, reducing arm weight and increasing speed; easy to add/remove disks for specific task requirements

3

# METHODOLOGY CHOICE OF SOLUTION

Method | Flexibility | Complexity | Verdict
Pneumatic | High | High (Pumps/Valves) | Rejected: Too bulky for a portable EDL project.
SMA (Shape Memory Alloy) | High | Very High (Thermal Control) | Rejected: Slow response time and cooling issues.
Tendon-Driven | High | Moderate | Selected: Best balance of precision, cost, and control.

# Methodology & Design Evaluation

# Why Tendon-Driven?

Remote Actuation
positions heavy motors at the base to minimize link inertia

Reliability
uses standard DC/Stepper motors for consistent, repeatable positioning

Scalability
easier to implement multi-segment control using a single microcontroller.

## Engineering Approach

## Requirement-Driven Design

prioritised high
bend-radius and low distal weight

## Bio-mimetic Modeling

modelled tendon routing
based on cephalopod
musculature.

## Iterative Selection

evaluated multiple actuation methods against EDL project constraints (portability, cost, and precision).

4

# SYSTEM OVERVIEW

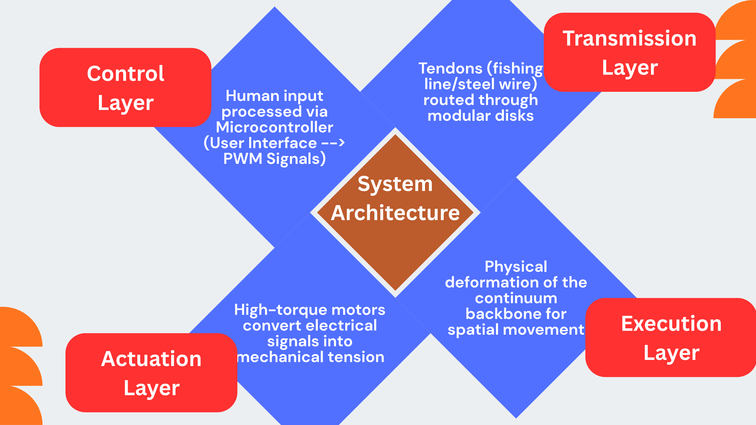
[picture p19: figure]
Human input processed via Microcontroller (User Interface --> PWM Signals); System Architecture; High-torque motors convert electrical signals into mechanical tension; Physical deformation of the continuum backbone for spatial movement; Tendons (fishing line/steel wire) routed through modular disks; Control Layer; Transmission Layer; Execution A Layer ctuation Layer

5

# CONTINUUM LINK

## Elastic Backbone

## Compliant Mechanism

Uses a flexible, springy
central spine that
provides structural
integrity while allowing
for multi-directional
bending and acts as a
spring to return the
robot to a neutral
position

Since the
robot is made
of springs, it
is naturally
soft and can
withstand
some amount
of stress

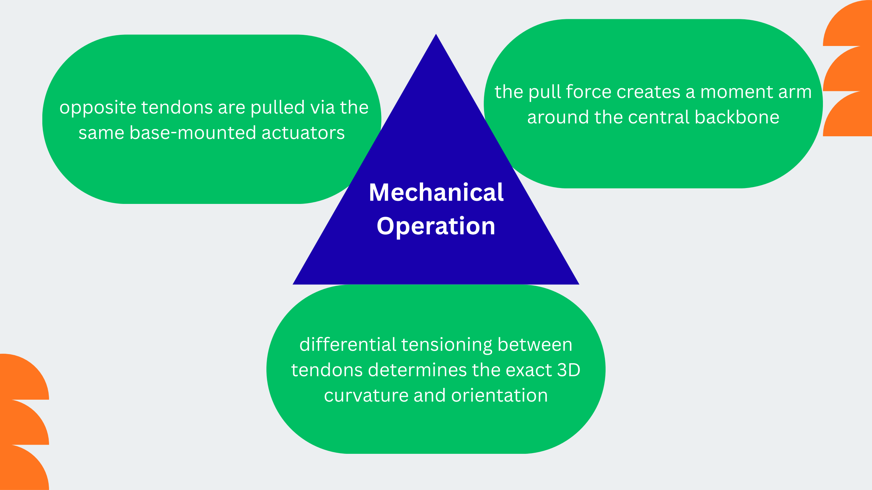
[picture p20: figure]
the pull force creates a moment arm; same base-mounted actuators; Mechanical Operation; differential tensioning between tendons determines the exact 3D curvature and orientation

around the central backbone opposite tendons are pulled via the

### Design Specifications

Loading
Capacity: Since
it is controlled
by fishing line as
strings, it can
take a lot of
strain

Deflection
Range: 90°
per segment

Target Bend
Radius: 7 cm

Number of
tendons per
link: 4

Backbone
Material:
PLA.

5

# TENTACLE END-EFFECTOR

## Decreasing Link Length

## Hard Subsections

the subparts
scale down,
which naturally
curls it into a
spiral

the links are made
of 3-D printed
plastics but are
held in place using
strings, which
ensure even tension
while gripping

2 peripheral holes placed at opposite sides

each link is designed to be independently linked to the others with minimal tension

## Anatomy of Subsection

## Pivot

## Tendon Ports

## Design Characteristics

modular rigid subsections arranged along a flexible, tendon-constrained backbone

tendon-based coupling ensures even force distribution and coordinated bending and gripping

progressively
decreasing link
dimensions introduce
a natural spiral
curvature under
tension

3D-printed PLA
components used for
rapid prototyping
and geometric
iteration

6

# ACTUATION + ELECTRONICS

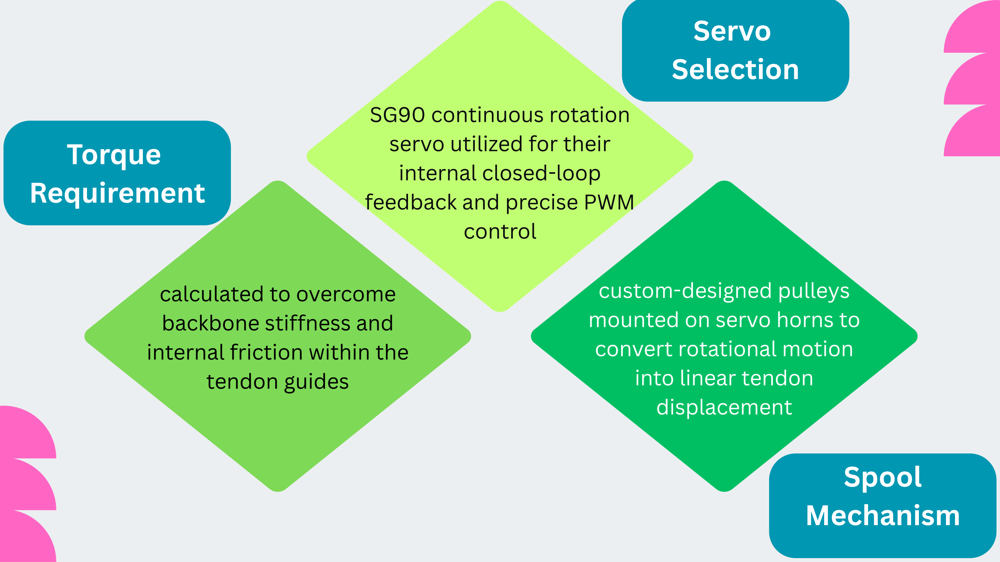
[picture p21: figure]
Servo Selection; SG90 continuous rotation servo utilized for their internal closed-loop feedback and precise PWM control; Torque Requirement; Spool Mechanism; calculated to overcome backbone stiffness and internal friction within the tendon guides; custom-designed pulleys mounted on servo horns to convert rotational motion into linear tendon displacement

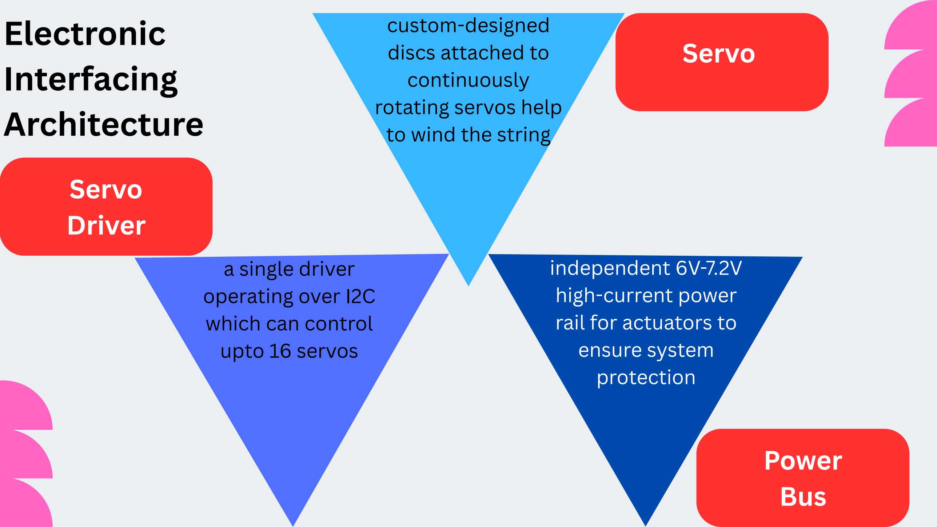
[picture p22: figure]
Electronic Interfacing Architecture; Servo; Servo Driver; Power Bus; custom-designed discs attached to continuously rotating servos help to wind the string; a single driver operating over I2C which can control upto 16 servos; independent 6V-7.2V high-current power rail for actuators to ensure system protection

# Microcontroller & Control Logic(3.3V)

## Processing Unit

## Driver Integration

RPi Pico was chosen over
other microcontrollers
because it was the most
familiar and convenient
with the breakout board;
ESP32 was chosen as a
backup due to the same
reasons

PCA9685 16-channel
servo driver used to
handle PWM generation
from the MCU

7

# BOM

Sr. | Name of Part | Req. Qty. + Spare | Unit Price | Total Cost
1 | Vinyl Tubing | 1 + 0 | 269 | 269
2 | Fishing Line | 1 + 0 | 252 | 252
3 | Continuously Rotating Servos | 9 + 1 | 142 | 1420
4 | Servo Driver | 1 + 0 | 230 | 230
5 | RaspberryPi Pico Microcontroller | 1 + 0 | 384 | 384
6 | ESP32 | 1 + 0 | 529 | 529
7 | Buck Converter | 1 + 0 | 398 | 398
8 | Power Adaptor 12V/5A | 1 + 0 | 419 | 419

## TOTAL: 3901

8

# JUSTIFICATION OF DESIGN CHOICE

## Reasoning

# Mechanical Choice

# 3D Printed Modular Links

## Benefit

### allows for rapid iteration(for spring

strength) and assembly.

### lightweight construction reduces the

gravitational load on the backbone, preventing droop.

## Reasoning

## Benefit

# Material Choice

# Nylon Tendons

### selected for high tensile strength and minimal longitudinal stretch

### ensures a direct 1:1 transfer of motion from the motor to the tip without slack

## Reasoning

## Benefit

# Microcontroller Unit Choice

# RPi Pico (backup ESP32)

MCU used for relaying info to the laptop,

### and RPi is familiar and easy to interface

### processing power provides the option to make it self-sufficient

# Actuation Choice

## Reasoning

## Benefit

# SG90 Servos

### easy interfacing and gear-reduction provide high holding torque

### necessary to maintain a bent posture against the restorative spring force of the backbone

9

# PROTOTYPING ITERATIVE DEVELOPMENT

build small-scale
models to identify
mechanical
bottlenecks early,
preventing expensive
failures in the final
build, and iteratively
modifying design and
realizing

# Prototyping Philosophy

started with 2D planar
bending before moving
to complex 3D spatial
orientation (tentacle
end-effector)

test every modular part
individually before full-scale integration

## Modular Validation

## Fail-Fast Methodology

## Incremental Complexity

# Continuum Link Prototype v2

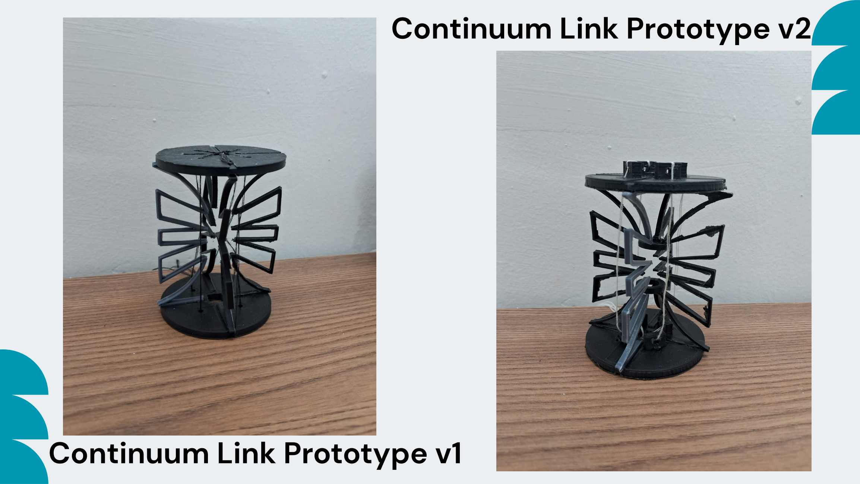
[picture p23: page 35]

# Continuum Link Prototype v1

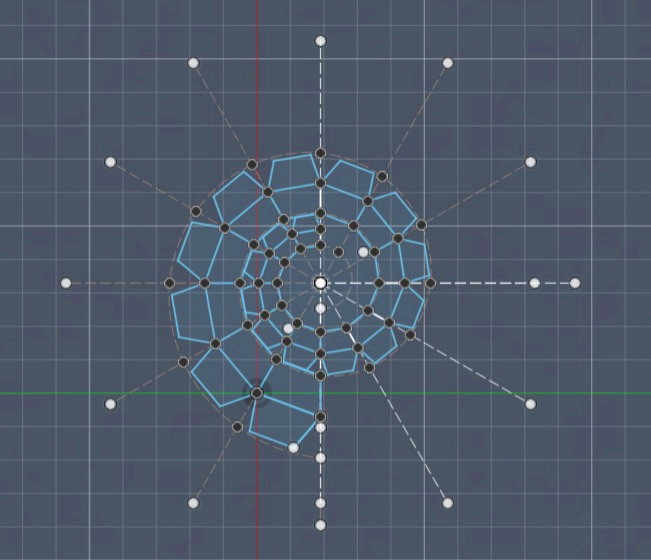
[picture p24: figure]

# Tentacle End-Effector Design

10

# TASK ALLOCATION GANTT CHART WEEKLY GOALS

Workstream | Team Members | Responsibilities
Structural Design of tentacle end effector | Arshit & Rishith | Design and fabrication of the tentacle segments and the final end-to-end finished gripper.
Structural Design of continuum robot | Veeresh | Task allocation to all the members and development of the central continuum robot structure.
Control Systems | Arijit & Prithvi | Motor bed assembly, MCU programming, and signal interfacing.

# Task Allocation & Team Roles

# Gantt Chart

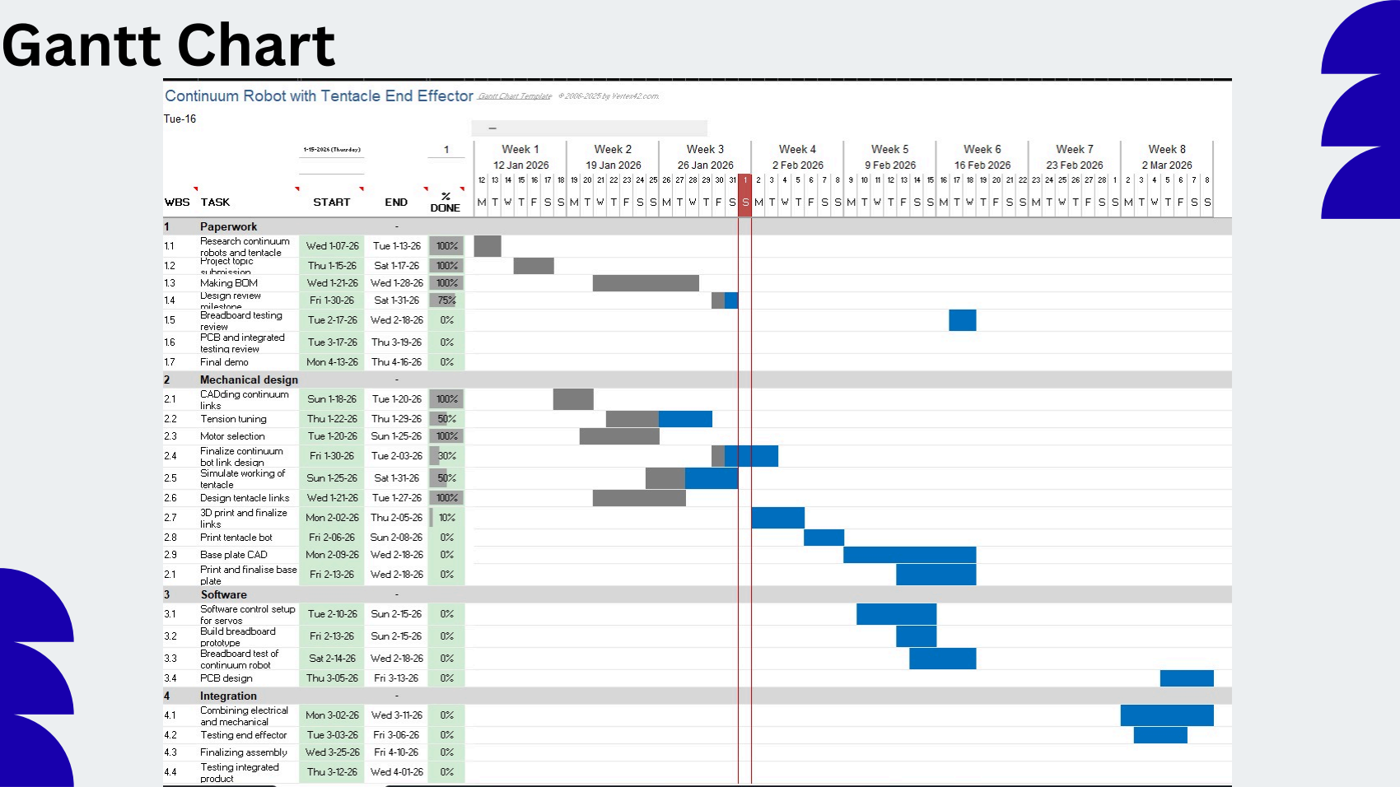
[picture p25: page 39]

# Gantt Chart

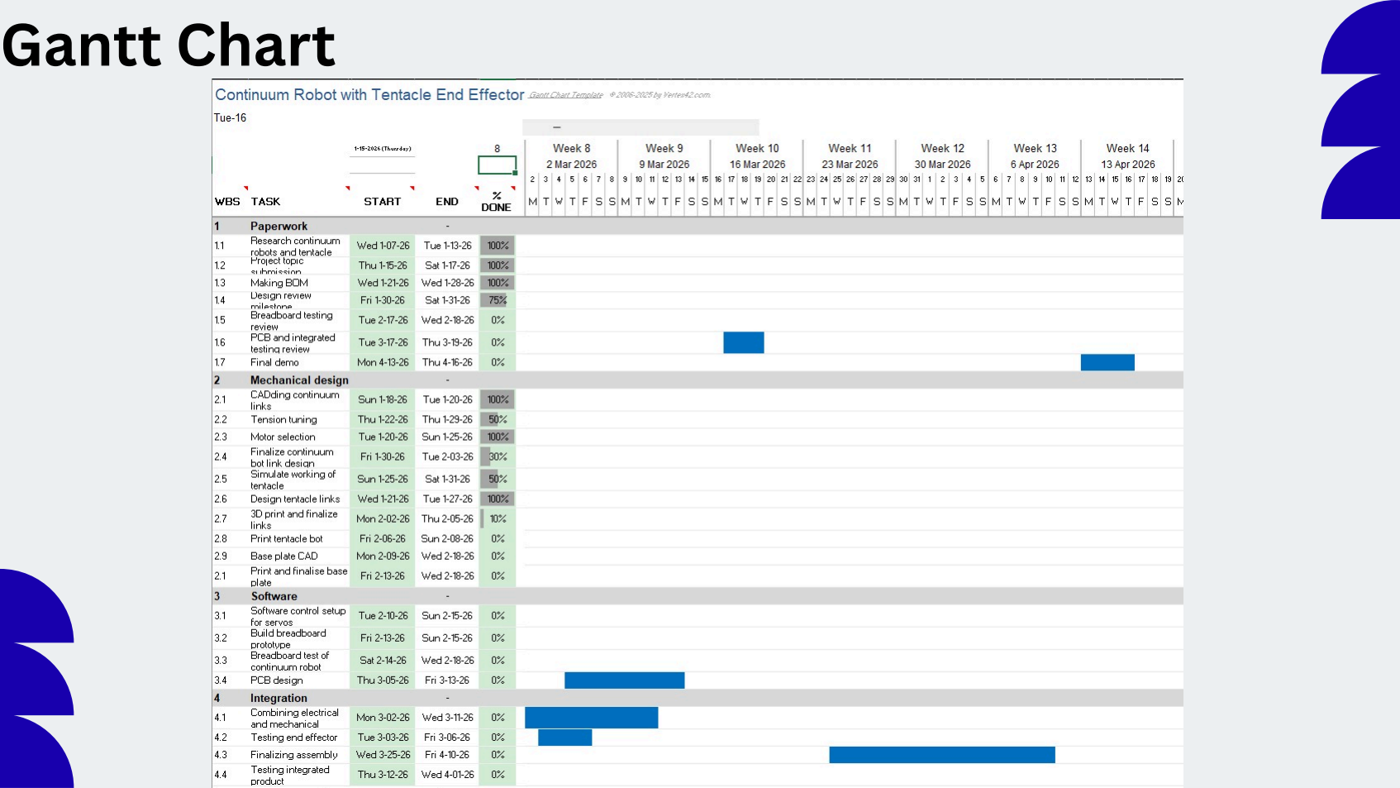
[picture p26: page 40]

Phase 1: Mechanical Finalization | Phase 2: Gesture contol
Preliminary Objectives | Extended Vision (if time permits)
- Get the whole continnum robot working without exessive bending | • Replacing laptop inputs with hand-tracking sensors.
- Get the tentacle end-effector working in 2D | • Fully untethered operation from manual laptop control.
- Getting the basic electronics working with the laptop | • Using cameras to grab objects using image detection

# Future Roadmap

11

# RISKS AND MITIGATION

Risk | Impact | Easy Mitigation Strategy
PLA Layer Splitting | High: Disks snapping under pressure | Horizontal Printing: print disks flat so the tendon force pulls across the layers, not against them
Nylon Thread Slipping | Medium: Tendons loosening at the motor | use "Figure-8" knots and a drop of superglue at the termination points.
Surface Friction | Medium: Jerky movement | internal hole are already smooth becasue of the way they are printed

# Risk Assessment & Mitigation

12

# FINAL DELIVERABLES

Compact,
tendon-driven
flexible arm
with adaptive
end-effector

Vision-based
gripping or
hand-gesture
control
(optional)

Base-mounted
motors with
open-loop
bending and
gripping control

Verified
bending, spiral
curvature, and
object gripping

Hybrid
Continuum–
Tentacle
Prototype

PROJECT
DELIVERABLES


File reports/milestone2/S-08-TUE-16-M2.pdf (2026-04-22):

# Hybrid Continuum-Tentacle Robotic Manipulator

## Circuit Schematics and Preliminary Analysis

Veeresh S K, Rishith Gupta, Arshit Singh Prithvi Sangam Chakravarthy, Arijit Paul

TUE-16
S-08

April 14, 2026

Hybrid Continuum-Tentacle Robotic Manipulator | TUE-16 | 1/18

## Problem Definition and Proposed Approach

Traditional rigid manipulators struggle in narrow and constrained environments


Applications such as search & rescue and industrial inspection require flexible robots

A continuum manipulator has a continuously bending backbone rather than rigid joints


We propose a tendon-driven continuum manipulator for smooth and adaptable bending

A tentacle-like adaptive end-effector enables grasping objects of different shapes

## System Architecture Overview

The robotic system consists of the following main subsystems: Continuum Link Mechanism
Tentacle End-Effector
Electronics : Components and Integration Algorithm and Controls System

## Continuum Link


Tendon-driven continuum backbone with a modular vertebrae structure

Compliant structural design enables multi-directional bending motion

Proposed backbone material: hot glue stick (high compressive strength with low bending stiffness for flexibility)

Three design prototypes developed

## Continuum Link Prototypes


Prototype 1: Initial backbone design ;

Too sharp Edges, Low Compressive

strength


Prototype 2: Improved vertebrae

structure ; Low Compressive Strength


Prototype 3: No Problems as of now

## Tentacle End-Effector


Bio-inspired flexible gripper for object grasping

Initial concept: single-body TPU print, but reliable printing proved difficult initially

Adopted a segmented hinge-based mechanism to achieve controlled flexibility

Tested multiple materials: Resin (too brittle) and PLA (friction issues)

Implemented design adjustments to mitigate friction in PLA and improve motion

## Tentacle End-Effector Prototypes


TPU Single-body Prototype

; Not printed properly


Hinge Mechanism Design

(PLA) ; Friction and uneven

tension causes to give

undesirable start position


Resin Printed Prototype ;

Too brittle


PLA Prototype working with

adjustments

## Base Plate


## Electronics: Components and Integration

Vision and User Input: Camera feed is streamed to the laptop, allowing the operator to issue motion commands based on live visual feedback

Control Architecture: User inputs are sent to Raspberry Pi Pico W controllers, which process commands and drive the Adafruit FeatherWing motor driver

Sensing and Feedback: Motor encoders and limit switches are read through Raspberry Pi GPIO pins and two port expanders for additional input channels

Power System: A 12V SMPS powers the motors while a 3.3V regulator provides logic power for the control electronics

Next slide: Circuit diagram

## Circuit Diagram


## Justification for Sensors and System Components

Limit Switches: Detect contact and enforce motion limits for safe operation

Camera: Provides real-time visual feedback for operator-guided teleoperation

Motor Encoders: Provide position feedback for monitoring motor rotation

Motors: Generate tendon tension to produce controlled robot bending

Adafruit FeatherWing: Motor driver for controlling motor speed and direction

Raspberry Pi Pico W: Main controller for command processing and actuation

12V SMPS & 3.3V Regulator: Provide power for motors and logic electronics

## Electronics Testing

All Components individually tested


Port Expander testing


Testing RPi - Adafruit - motor - RPi

loop


Getting Encoder values from motor

## Schematics and PCB

Circuit schematics were developed through multiple iterative design revisions

The PCB design is currently undergoing iterative refinement to improve routing, integration, and overall reliability


Circuit schematic design


PCB layout iteration

## Control Algorithm and Architecture

System Control Architecture

GUI sends direction and speed commands to the Master RPi via UART

The Master processes commands and determines motor actuation signals
PWM signals drive motor controllers, actuating the tendon-driven continuum links Encoder feedback from the Slave RPi is sent to the Master RPi for monitoring

Key Control Features
Closed-loop control with encoder feedback at 10 Hz for real-time monitoring Limit-switch safety constraints prevent motion beyond mechanical limits Compensation logic redistributes actuation when a link’s motion is restricted Differential motor actuation enables coordinated bending of continuum links

## Control Algorithm Overview


## Algorithm and Controls System


Using the endoscope for camera feed and testing transmission to Microcontroller

## Next Milestone Work Plan

Mechanical Development
Finalize continuum link and tentacle end-effector CAD design and geometry Fabricate updated mechanical prototypes using WEL 3D printing facilities

Electronics Development
Complete PCB design iterations and finalize the schematic and layout Fabricate the final PCB using the IIT Bombay PCB Lab facilities

Control Software Development

Implement the control algorithm and motor actuation mapping in MicroPython Develop firmware for both Master and Slave Raspberry Pi control units

## Final Deliverables

Hybrid Continuum–Tentacle Robotic Prototype
A complete robot demonstrating continuum bending and adaptive object grasping Navigation and Retrieval Demonstration
Robot moves through a constrained path and retrieves a target object User-Controlled Operation
Robot movement controlled through GUI commands with live camera feedback Integrated Mechatronic System
Combined operation of mechanical structure, electronics, sensors, and control

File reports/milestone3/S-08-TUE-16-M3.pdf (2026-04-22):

# Hybrid Continuum-Tentacle Robotic Manipulator

## Project Progress and System Readiness

Veeresh S K, Rishith Gupta, Arshit Singh Prithvi Sangam Chakravarthy, Arijit Paul

TUE-16
S-08

March 21, 2026

Hybrid Continuum-Tentacle Robotic Manipulator | TUE-16 | 1/11

## Feedback & Actions from Milestone 2

Feedback 1: High friction between nylon line and vinyl tubing

Action taken: Updated CAD design to avoid sharp degree turns
Feedback 2: Mechanical interference in motor-base plate assembly

Action taken: Modified base plate geometry to accommodate new tubing radii Feedback 3: High slide count and marketing-style presentation

Action taken: Consolidated slides to improve content density, add visual cues and prioritised technical details over decorative formatting

## Proof of Concept Demonstration

Demonstrates working proof of concept Shows actuation and basic functionality

Confirms feasibility of design


Click on the thumbnail for video

## PCB Readiness


Current Status

PCB schematics and layout completed

Design reviewed and iterated
Final design submitted to IITB PCB Lab

Key Design Improvements
Reduced trace lengths for integrity Ground planes on both PCB layers

Improved decoupling placement Key Learnings
Proper grounding reduces noise Routing impacts signal stability

## Final PCB Layout


Figure: Final PCB layout with optimized routing and grounding

## CAD Readiness for Assembly of Prototype

Current Status


All components fabricated and available Test-fitted for clearances and tolerances

Tendon routing and actuator mounts implemented

Assembly Readiness
Mounting interfaces finalized
Cable routing paths defined

Modular subsystem assembly enabled

## Critical Tasks In Progress

System Integration: Electronics routing and subsystem interfacing

Control Tuning: Interrupt-based control with encoder feedback Tendon Calibration: Tension tuning for symmetric bending System Testing: End-to-end validation with GUI and camera

Completed Preparatory Work

Mechanical subsystems tested and partially assembled Motors, encoders, and port expanders tested individually PCB design completed and sent for fabrication

## Key Risks Yet To Be Addressed

Mechanical Friction: Joint friction in tentacle segments may hinder smooth motion Tendon Actuation Limits: Bending paths may reduce effective tendon force Algorithmic Latency: Control logic may exceed ISR timing limits

Encoder Reliability: Noise or missed counts may affect position accuracy

Mitigation Strategies

Incremental Testing: Validate control loop one axis at a time
Timing Profiling: Verify ISR execution using logic analyzer Mechanical Tuning: Optimize tendon routing and reduce joint friction

## Progress vs Test Plan (Gantt Chart)


Most milestones on schedule
Minor delay in Control Algorithm
Mechanical and electrical design progressed faster than planned

## Work Distribution Until Final Demo

Member | Responsibility | Key Tasks
Arshit | Control Algorithm | Interrupt logic, motor control
Prithvi | Control Algorithm | Encoder handling, control tuning
Rishith | Mechanical Assembly | Tentacle assembly and calibration
Veeresh | Mechanical Assembly | Continuum assembly and actuation setup
Arijit | Electrical Assembly | Wiring, PCB integration

Parallel development of mechanical, electrical, and control subsystems Staged integration with testing after each subsystem merge

Final system-level validation before demonstration

## Plan for Final Demonstration

Demonstration Sequence

Fully integrated hybrid continuum–tentacle robotic system User control via GUI with live camera feed
Controlled multi-directional bending using tendon actuation

Navigation through a constrained path and object grasping

Evaluation Metrics
Consistent and repeatable continuum bending response
Successful object grasping and retrieval in test environment

Reliable integration of mechanical, electrical, and control subsystems

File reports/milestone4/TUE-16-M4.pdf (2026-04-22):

# Secure Adaptive Continuum Explorer


## VEERESH

S

K

(23

B1309)

## RISHITH GUPTA

(23

B1234)

## ARSHIT SINGH

(23

B1275)

## PRITHVI SANGAM

(23

B1292)

## ARIJITPAUL

(23

B1219

)

# TUE

1

6

01
02
03

# SUMMARY

# WHAT?

# WHO?

# PROBLEM?

## modular continuum tentacle-based end-effector using tendon-driven actuation and visual feedback

## industrial maintenance, medical/surgical researchers and rescue professionals requiring flexible robotic systems

overcomes limited accessibility and dexterity,

## adaptive grasping and safe interaction

02

# SPECIFICATIONS

## 01 LINK BENDING : 30°

## EXTENSION OF : 40 cm LEADSCREW

## 03 CAMERA FOV : 60°

04

05

## MINIMUM GRABBING : 1.25 cm RADIUS

## MAXIMUM GRABBING : 3.5 cm RADIUS

### Key Requirements proposed at the beginning of the semester

### Status at end of semester

### Remarks/Justification

### bending of individual

continuum links | complete
end-effector object gripping | complete

### hybrid continuum-tentacle

mechanical design | complete

# STATUS OF PROJECT

### Key Requirements proposed at the beginning of the semester

### Status at end of semester

### Remarks/Justification

### user control through GUI commands on keyboard with live camera feedback

### complete

### limit switch-based obstacle

avoidance | complete

# STATUS OF PROJECT

### Key Requirements proposed at the beginning of the semester

### Status at end of semester

### Remarks/Justification

integrated multiple RPis and ICs | complete

### autonomous navigation, control

and object retireval | incomplete

### manual control algorithm complex, and more costly sensors required

# STATUS OF PROJECT

# PHOTOGRAPHS OF FINAL PROTOTYPE



## PCB

## CONTINUUM LINKS

EN

T
D

E

N
EF

TA

## EF C

C

L
T

E
OR

## LEADSCREW

## PILLOW BEARING

## COUPLERS

## BASE PLATE WITH MOTORS

## LIMIT SWITCHES

## ENDOSCOPE CAMERA

## MOTOR DRIVER


## MASTER RPI LEADSCREW MOTOR

# CONTINUUM BENDING TO THE LIMIT !!!


# CHALLENGES FACED AND HOW WE SOLVED THEM

spool design; tentacle material

Challenges | Solutions | Remarks

multiple iterations, 2 winding spool with opposite directions

working but better
solutions possible

choice and design

final design hinge-based,
printed in PLA, tried resin printing

effective bending and
movement

insufficient ports on
RPi Pico

used port expanders and
master-slave architecture

increased ports (26 to
26+32) and better task
distribution

realised torque was
less

changed routing of cables and
brought motors to base plate getting enough torque

mistakes in PCB design

Challenges | Solutions | Remarks

fixed using micro-surgery and removal of Vsys of main RPi

PCB is working
without any issues

defect in motors

micro-surgery to connect
terminals and connector

motor defect fixed
and working

double lead screw
alignment

keeping one lead screw
stationary, moving other

better movement
than earlier

tight mechanical
tolerances

changed designs and 3D
printers for better prototype

more flexible and
accurate design

# CHALLENGES FACED AND HOW WE SOLVED THEM

# DEMO VIDEO


# MINDS


# BEHIND THIS

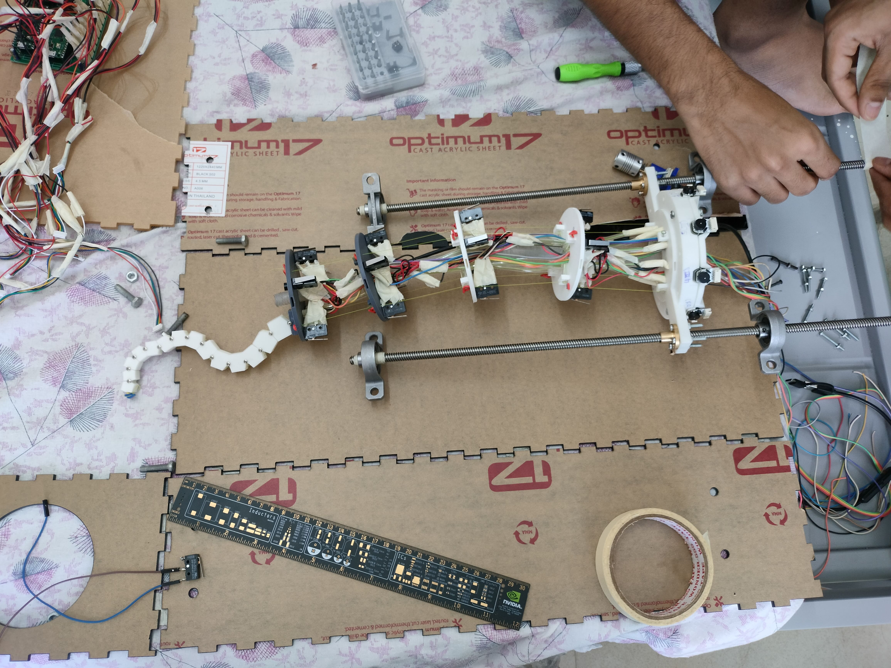
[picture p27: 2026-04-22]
others/extras/images/mechanical_backbone.jpg

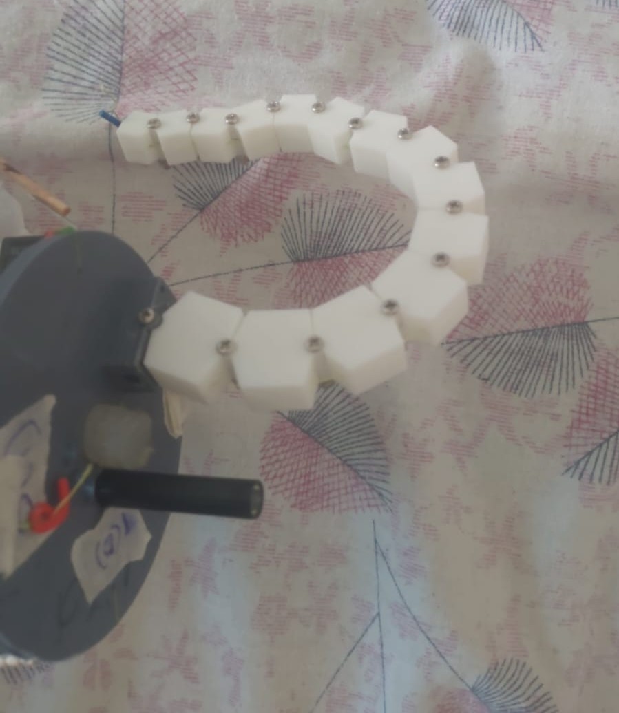
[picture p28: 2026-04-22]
others/images/tentacle_end_effector.jpeg

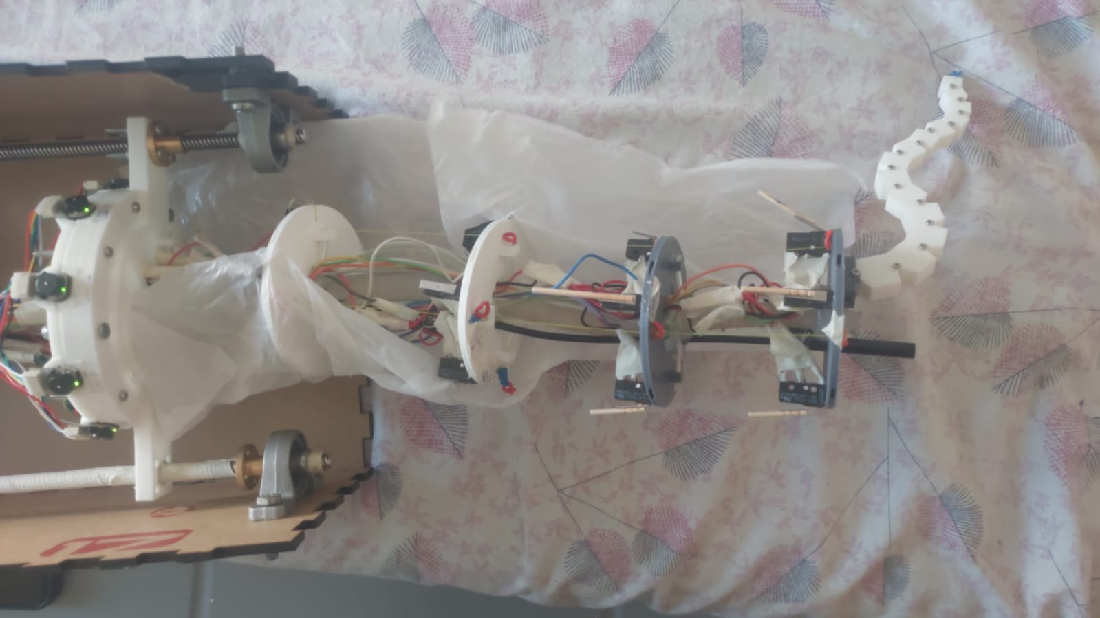
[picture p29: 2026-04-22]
others/images/full_bot.jpeg

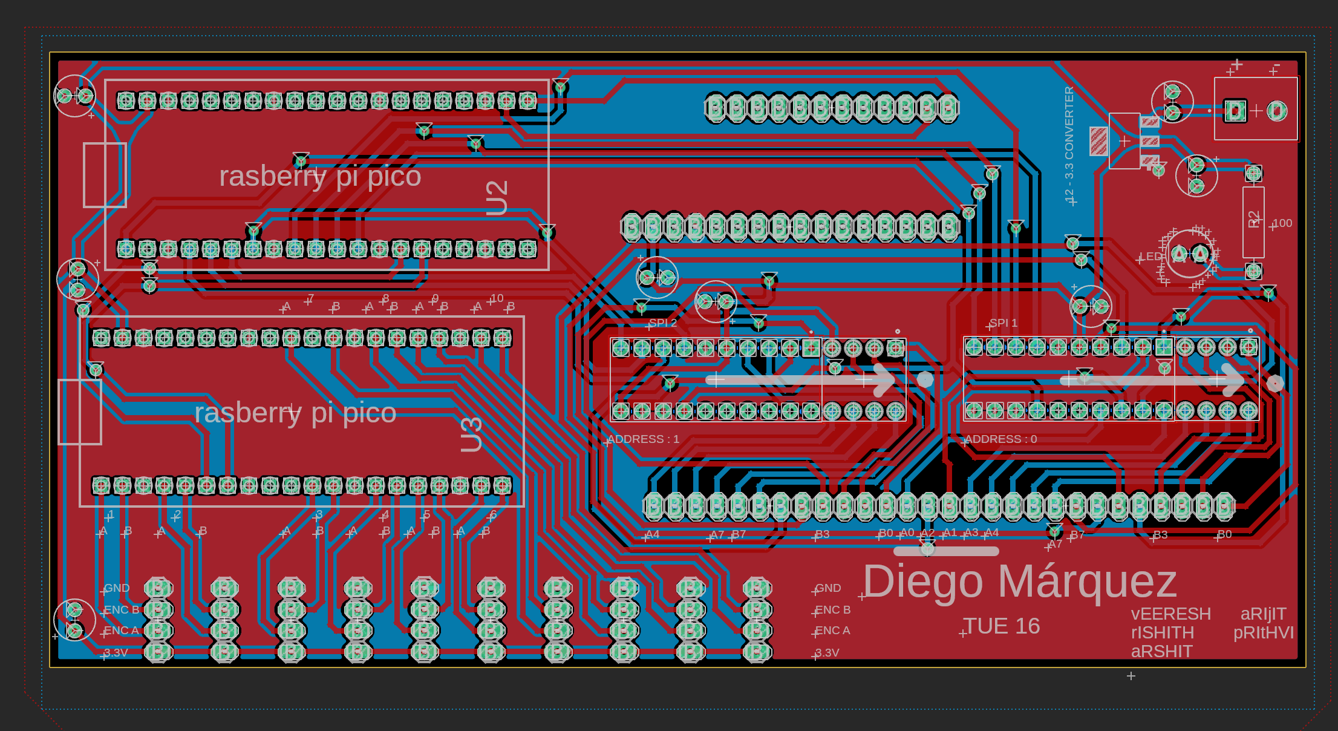
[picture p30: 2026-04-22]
pcb/PCB1/pictures/pcb layout in fusion.png

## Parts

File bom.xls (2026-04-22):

Project Title: Continuum Robot with tentacle end effector
Group ID: TUE-16
Name of the Group Member/s: Veeresh S K, Arijit Paul, Arshit Singh, Rishit Gupta, Prithvi Sangam Chakravarthy
Contact details (name, phone number, email ID) of the Group Member responsible for BOM: (Veeresh S K, 8762443930, 23b1309), (Arijit Paul, 9582745917, 23b1219)
BOM
Sr.No | Use case/Function | Part description | Manufacturing Part Number | Package type/Footprint | Available in WEL? | WEL Component stock Location-ID | Vendor | Stock availability (With Vendor) | Link (Vendor online website) | Required Qty + Spare | Cost per item | Total Cost
ELECTRONICS
1 | Controlling the motor driver | R-Pi Pico W | SKU: 894292 | Development board | Yes | 1M | Robu | Out of stock | https://robu.in/product/raspberry-pi-pico/ | 2+1 | 384 | 1152
2 | Controlling the motors | Adafruit Featherwing Motor Driver | 2927 | Development board | Yes | Wel 3 Ankur Sir | Mouser | In stock | https://www.mouser.in/ProductDetail/Adafruit/2927?qs=ivJcBTDythUMt4thpvI5VA%3D%3D | 3+1 | 1792 | 7168
3 | Sensor to detect touch | Limit switches | SKU: 52769 | Limit switch | No | NA | Robu | In stock | https://robu.in/product/3d-printer-limit-switch-endstop-omron-ss-5gl/ | 24+10 | 51 | 1734
4 | To see the goal/navigate the bot | camera | SKU:1165415 | Endoscope camera | No | NA | Robu | In stock | https://robu.in/product/7mm-3-in-1-hd-android-mobile-phone-endoscope-1m-waterproof-ip67-6-leds-usb-inspection/ | 1+0 | 720 | 720
5 | Motors for moving the bot | Motor | GA12 N20 | Motor | No | NA | Robu | In Stock | https://robu.in/product/n20-12v-120rpm-micro-metal-gear-motor-with-encoder/# | 11+1 | 566 | 6792
6 | Writing control signals to Motors | I/O Expander | SKU: 1089297 | DIP-28 | No | NA | Robu | In Stock | https://robu.in/product/mcp23s17-e-sp-16-bit-input-output-expander-with-i2c-interface-ic-dip-18-package/ | 2+1 | 319 | 957
7 | Convert 12V to 3.3V | Voltage Regulator | NA | LD1117 SOT 223 | Yes | Wel 1 Capat-5-.BOX-12.4 | Mouser | In stock | https://www.mouser.in/c/semiconductors/power-management-ics/voltage-regulators-voltage-controllers/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 | 1+0 | 30 | 30
8 | Power Supply | Power Supply | RMCS-4012 | Power Supply | No | NA | Robokits | In Stock | https://robokits.co.in/power-supply/industrial-power-supply/industrial-power-supply-12v-10a-120w-premium | 1+0 | 700 | 700
MECHANICAL
9 | Routing strings to motors | Vinyl tubing | B09C6F8M22 | 2.5 x 4mm, 10m PU hose | No | NA | Amazon | In stock | https://www.amazon.in/Pneumatic-Compressor-Blue10M-Polyurethane-Transplant/dp/B09C6F8M22 | 1+0 | 269 | 269
10 | Thread for controlling the robot | Fishing Line | ?AZBD2-10OTJ6F | 100m Nylon String | No | NA | Amazon | In stock | https://www.amazon.in/ZORBES%C2%AE-Invisible-Abrasion-Resistant-Monofilament/dp/B0CX8KPFFD?s=sports | 1+0 | 252 | 252
11 | attaches motor to leadscrew | Flexible coupling | SKU: 921904 | Flexible coupling | No | NA | Robu | In stock | https://robu.in/product/flexible-coupling-od20mm-x-l25mm-bore-5-x-10mm/ | 4+0 | 68 | 272
12 | moving the robot out | lead screw | SKU: 501497 | Lead screw | No | NA | Robu | In stock | https://robu.in/product/500mm-trapezoidal-4-start-lead-screw-10mm-thread-2mm-pitch-lead-screw-with-copper-nut-copy/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 | 2+0 | 385 | 1440
13 | attaches robot to leadscrew | pillow bearing | SKU: 52357 | Pillow black bearing | No | NA | Robu | In stock | https://robu.in/product/10mm-bore-inner-ball-mounted-pillow-block-insert-bearing-kp000/?gad_source=1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 | 2+0 | 106 | 212
14 | 3D printing | 3D printer filament | SKU: R254806 | Spool | Yes | 3D Printers | Robu | Out of stock | https://robu.in/product/esun-pla-basic-filament-2/ | 1+0 | 786 | 786
15 | Backbone | Glue stick | NA | NA | No | NA | Amazon | In stock | https://www.amazon.in/Mario-Milky-Glue-Adhesive-220mm/dp/B0DTTBV41K | 1+0 | 188 | 188
16 | Assembly of tentacle | M2 Screws | NA | NA | No | NA | Local | In stock | Near Fish Market, Gokhale Nagar, Chaitanya Nagar, Tirandaz, Powai, Mumbai, Maharashtra 400076 | 14 | 2 | 28
17 | Assembly of tentacle | M2 Nuts | NA | NA | No | NA | Local | In stock | Near Fish Market, Gokhale Nagar, Chaitanya Nagar, Tirandaz, Powai, Mumbai, Maharashtra 400077 | 28 | 2 | 56
18 | Making enclosure | Acrylic Sheet 6mm | NA | NA | Yes | Laser Cutting Machine | Local | In stock | Near Fish Market, Gokhale Nagar, Chaitanya Nagar, Tirandaz, Powai, Mumbai, Maharashtra 400078 | 1 | 300 | 300
19 | Assembly | Masking Tape | NA | NA | Yes | Wel 1 Capat-5-.BOX-10.1 | Local | In stock | Near Fish Market, Gokhale Nagar, Chaitanya Nagar, Tirandaz, Powai, Mumbai, Maharashtra 400079 | 1 | 100 | 100
20 | Fixing PCB | Double-sided Tape | NA | NA | No | NA | Local | In stock | Near Fish Market, Gokhale Nagar, Chaitanya Nagar, Tirandaz, Powai, Mumbai, Maharashtra 400080 | 1 | 30 | 30
21 | Assembly of base plate and its cap | M4 Screws | NA | NA | No | NA | Local | In stock | Near Fish Market, Gokhale Nagar, Chaitanya Nagar, Tirandaz, Powai, Mumbai, Maharashtra 400081 | 9 | 4 | 36
22 | Assembly of base plate and its cap | M4 Nuts | NA | NA | No | NA | Local | In stock | Near Fish Market, Gokhale Nagar, Chaitanya Nagar, Tirandaz, Powai, Mumbai, Maharashtra 400082 | 9 | 4 | 36
23 | Assembly of leadscrew with enclosure | M6 Screws | NA | NA | No | NA | Local | In stock | Near Fish Market, Gokhale Nagar, Chaitanya Nagar, Tirandaz, Powai, Mumbai, Maharashtra 400083 | 4 | 5 | 20
24 | Assembly of leadscrew with enclosure | M6 Nuts | NA | NA | No | NA | Local | In stock | Near Fish Market, Gokhale Nagar, Chaitanya Nagar, Tirandaz, Powai, Mumbai, Maharashtra 400084 | 4 | 5 | 20
25 | Assembly of leadscrew to base plate | M3 Screws | NA | NA | No | NA | Local | In stock | Near Fish Market, Gokhale Nagar, Chaitanya Nagar, Tirandaz, Powai, Mumbai, Maharashtra 400085 | 8 | 3 | 24
26 | Assembly of leadscrew to base plate | M3 Nuts | NA | NA | No | NA | Local | In stock | Near Fish Market, Gokhale Nagar, Chaitanya Nagar, Tirandaz, Powai, Mumbai, Maharashtra 400086 | 8 | 3 | 24
 |  |  |  |  |  |  |  |  |  |  | Total | 23346

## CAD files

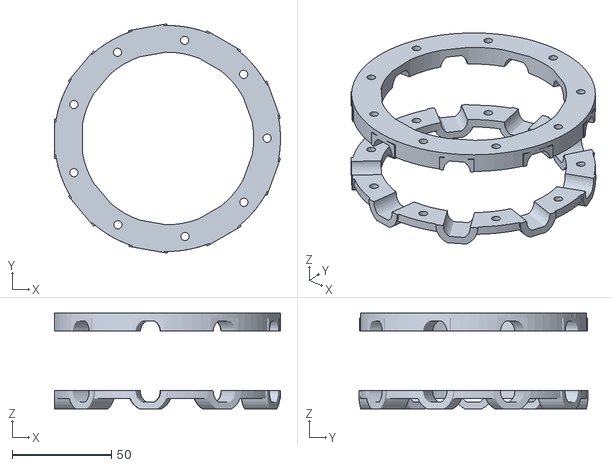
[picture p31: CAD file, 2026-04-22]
3d_models/base_plate/Base plate_it 2.stl
114.0 x 115.7 x 48.2

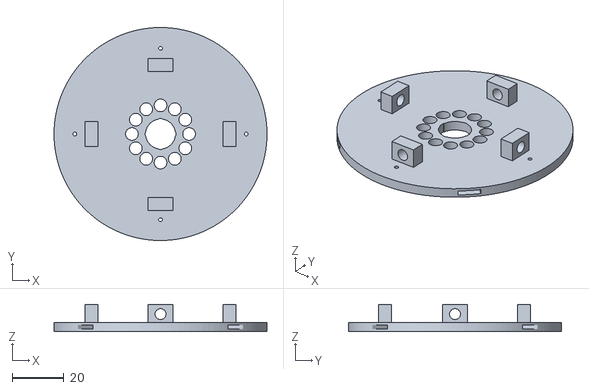
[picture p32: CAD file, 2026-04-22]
3d_models/continuum_robot/Base_Link.stl
82.0 x 82.0 x 10.4

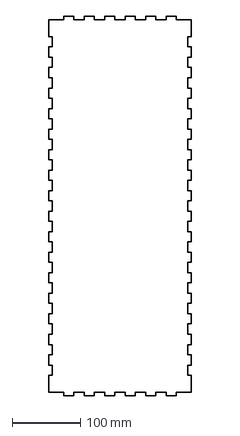
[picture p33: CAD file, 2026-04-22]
3d_models/enclosure/top.dxf
208.0 x 555.0 mm

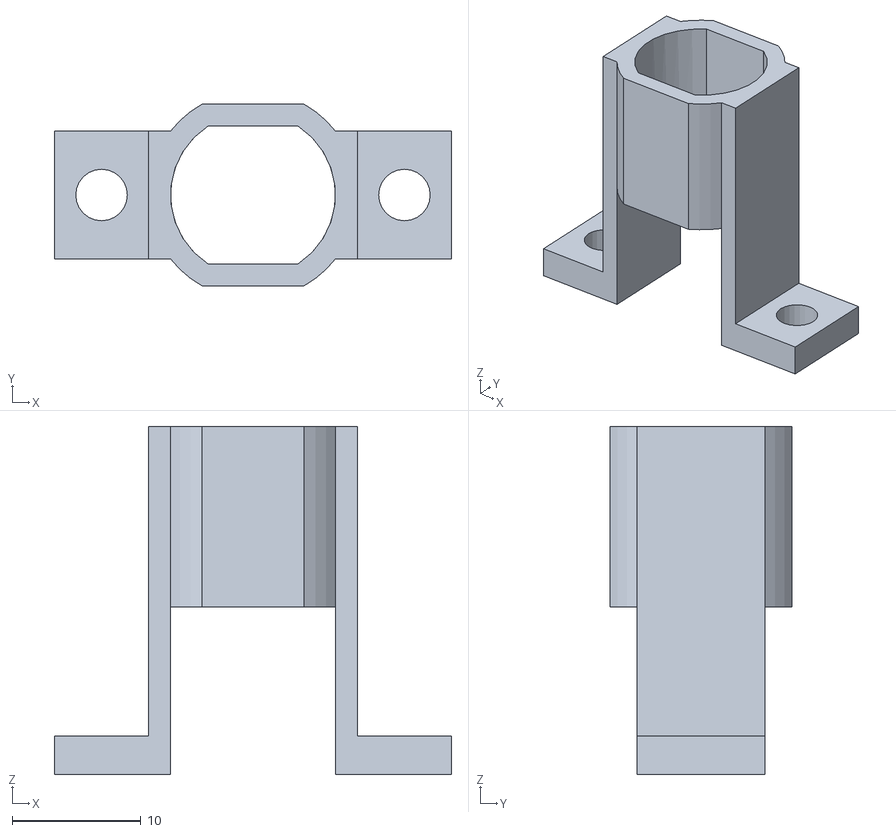
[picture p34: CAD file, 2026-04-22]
3d_models/Motor Mount/Motor_mound.stl
30.8 x 14.1 x 27.0

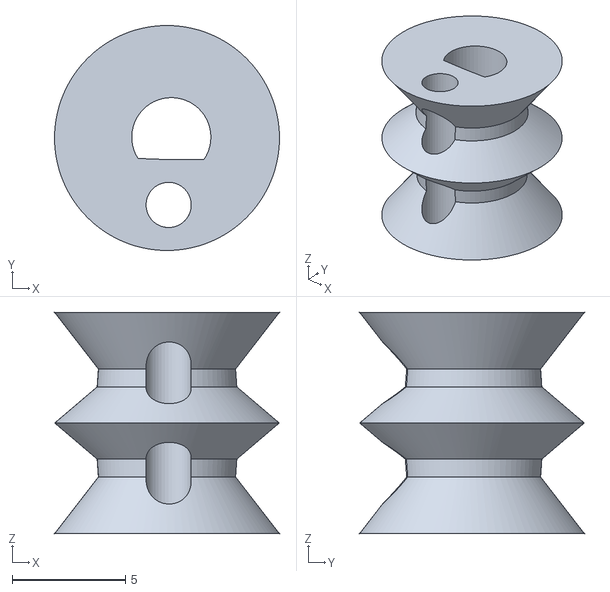
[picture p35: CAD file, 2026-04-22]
3d_models/spool/spool.stl
9.95 x 9.95 x 9.80

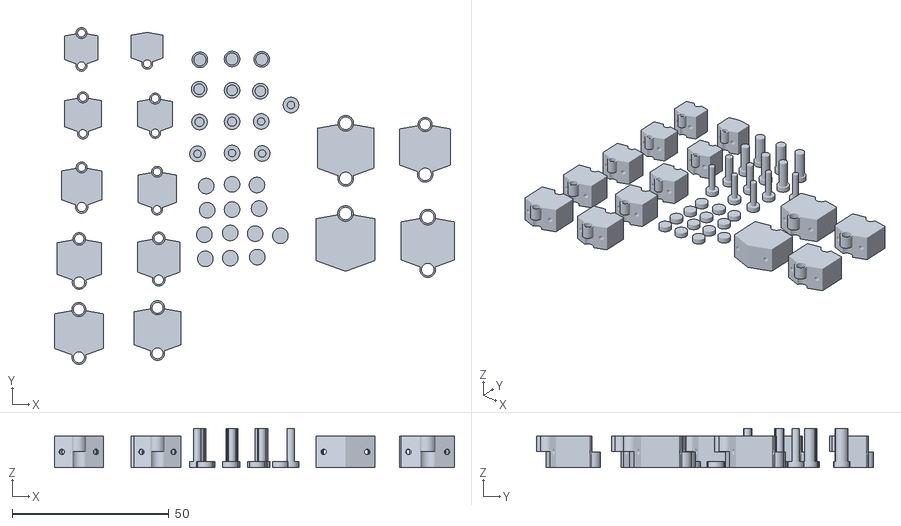
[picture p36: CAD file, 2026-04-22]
3d_models/tentacle and top_link/Tentacle.stl
127.7 x 107.5 x 12.5

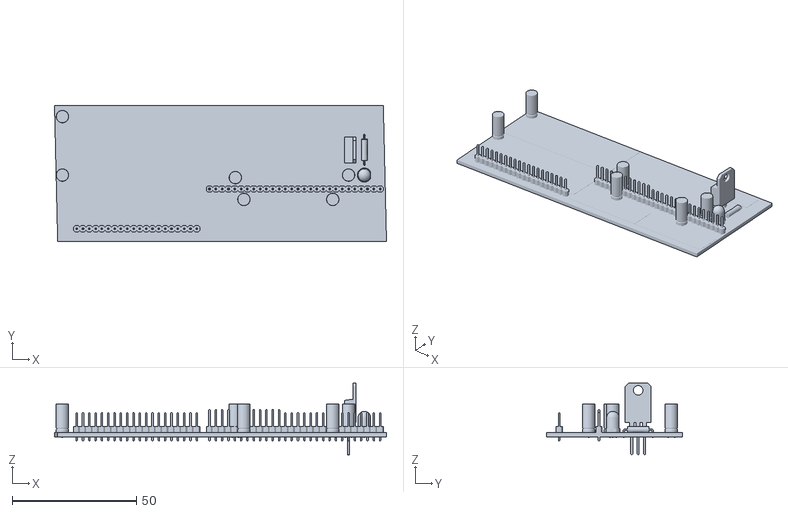
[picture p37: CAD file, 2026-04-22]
pcb/PCB1/PCB_3d.stl
133.3 x 54.6 x 28.9

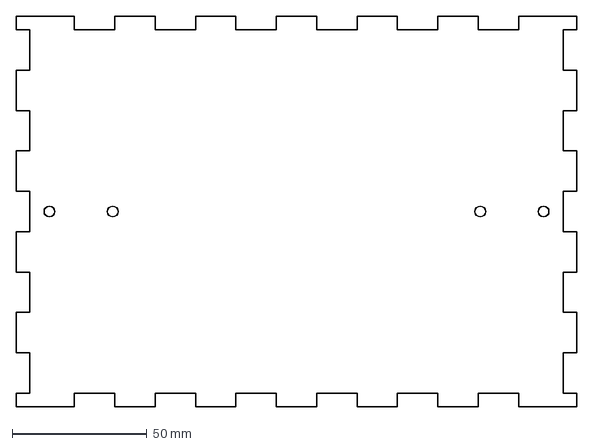
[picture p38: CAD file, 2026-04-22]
3d_models/enclosure/back.dxf
208.0 x 145.0 mm

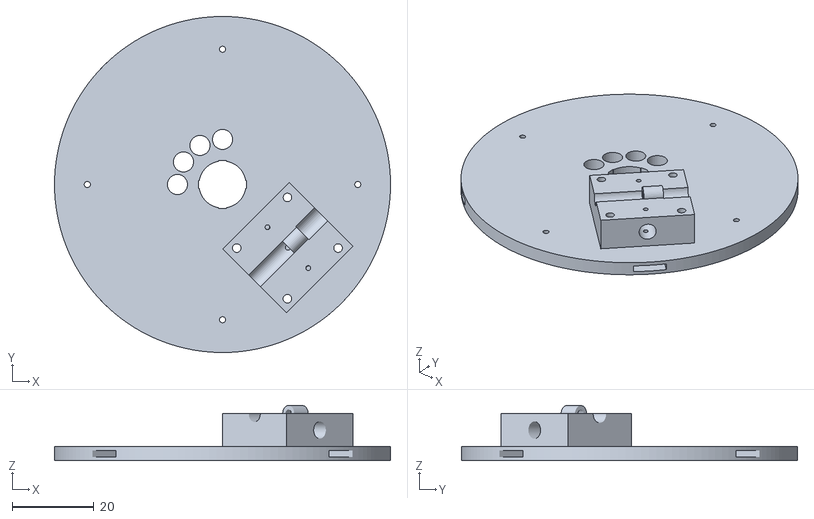
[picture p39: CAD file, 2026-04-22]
3d_models/tentacle and top_link/tentacle_link.stl
82.0 x 82.0 x 13.4

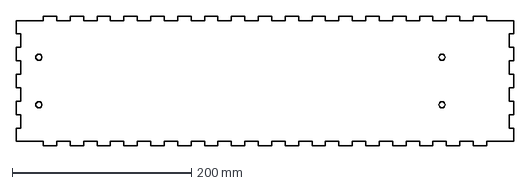
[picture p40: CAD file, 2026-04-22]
3d_models/enclosure/side.dxf
555.0 x 145.0 mm

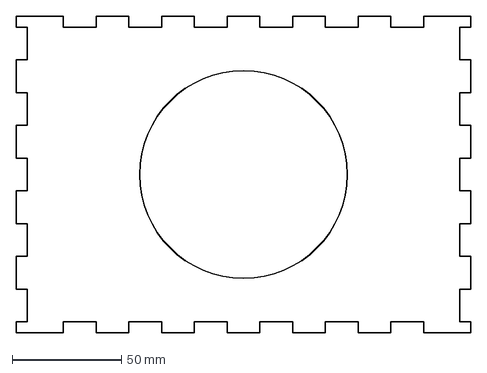
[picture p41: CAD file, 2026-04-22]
3d_models/enclosure/front.dxf
208.0 x 145.0 mm

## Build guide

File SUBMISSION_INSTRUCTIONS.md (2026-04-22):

# Project Documentation and Submission Guide

This document serves as a comprehensive guide for your project submission. By following the instructions below, you will ensure that the project is properly organized, documented, and easy for others (such as professors or staff members) to understand and replicate.

Your entire project is graded based on this submission and so please adhere to this properly. Stick to the hard deadline given and NO EXTENSIONS WILL BE GRANTED AT ANY POINT IF IT IS NOT COMPLETED.

## Project Overview

### Project Name: [Insert Project Name Here]
### Team Number: [MON/TUE-xx]
### Team Members:
- [Name 1]
- [Name 2]
- [Name 3]
- [Name 4]
- [Name 5] (if applicable)

### Problem Statement and Solution:

Provide a description about the project and what you've learnt and achieved in this.

Make sure to add all the below properly as given and if it's applicable.

## 1. Source Code

All source code files should be organized under the `/src` directory. If your project involves multiple microcontrollers or processors, create respective subfolders for each and provide clear descriptions about their purpose and functionality. Every subfolder should have a README.MD file which should explain the purpose of the code and all the commands used.

### Folder Structure:
```plaintext
/Project-Root 
├── /src # Source code folder (Add your source files here) 
  ├── /microcontroller1 # Code for Microcontroller 1 
    ├── file1.c # General source file 
    ├── file2.c
  ├── /microcontroller2 # Code for Microcontroller 2 (if applicable) 
    ├── file1.c # General source file 
    ├── file2.c
```

### Guidelines for Organizing Code:
1. **Microcontroller-specific code**:  
   If your project involves multiple microcontrollers, create a folder for each one under `/src`. Provide the following details:
   
   - **Folder Name**: Name it according to the microcontroller, e.g., `Microcontroller1`, `Microcontroller2`.
   - **Description**: A brief description of what each microcontroller’s source code does and its role in the project in a README.md file.

Example:
```plaintext
/src 
  ├── /<microcontroller_name1> 
    ├── <relevant_sources.c>  # All source codes
    ├── README.md  # Clear Documentation on the usage of board along with the commands and steps performed
  ├── /<microcontroller_name2> 
    ├── <relevant_sources.c>  # All source codes
    ├── README.md  # Clear Documentation on the usage of board along with the commands and steps performed
......
......
```

2. **Running the Application**:
- If your project is based on microcontroller code, provide detailed instructions on how to upload and run the code on the microcontroller. This should include:
  - The microcontroller model (e.g. STM32, RPi Pico).
  - The Integrated Development Environment (IDE) used for programming (e.g., STM32CubeIDE, VSCode, Thonny IDE).
  - Steps for compiling and uploading the code to the device.
  - Example command to upload (if applicable).

3. **Code Comments**:
- Every source file should be properly commented to describe the purpose and function of each section of code.
- If you have made modifications to an existing code template or framework, comment clearly with your team name and indicate what changes were made.

---

## 2. PCB Design (If Applicable)

If your project involves designing a printed circuit board (PCB), provide the design files in the `/pcb` folder. If you have multiple PCBs, create separate subfolders for each design. Mention the tool used to design the PCB. (KiCAD, Altium, EAGLE). Include the picture of your final PCB Layout (With visibility of all the layers) under the `/pcb/<PCB_X>/pictures` folder with the layer names along with the picture of the Printed PCB which you've obtained.

### Folder Structure:
```plaintext
/Project-Root 
├── /pcb 
  ├── /PCB1 # First PCB Design 
    ├── design.kicad_pcb # PCB Design in KiCAD format 
    ├── schematic.sch # KiCAD Schematic 
  ├── /PCB2 # Second PCB Design (if applicable) 
    ├── design.sch # PCB Schematic
    ├── design.kicad_pcb # PCB Design in KiCAD format 
```
Include all relevant design files such as schematics, board layouts, custom schematic and footprints used and imported if applicable.

---

## 3. 3D Models / Laser Cuts

If your project includes 3D models or components that require laser cutting, place these files in the `/3d_models` directory. Create separate subfolders for different models and provide a description of the design process and tools used.

### Folder Structure:
```plaintext
/Project-Root 
├── /3d_models 
  ├── /component1 # 3D Model for Component 1 
    ├── model.stl # 3D model file 
    ├── picture.png # Rendered image of the 3D model 
  ├── /component2 
    ├── model.obj 
    ├── picture.jpg
```
Make sure to also include images (e.g., PNG, JPG) of the components that were laser cut or 3D printed.

---

## 4. Bill of Materials (BOM)

Provide a complete Bill of Materials (BOM) listing all the hardware components used in your project. This should include both parts obtained from the lab and parts ordered from external vendors or purchased locally.

### Folder Structure:
```plaintext
/Project-Root 
├── bom.xls # Excel sheet listing components
```

### BOM Details:
The `bom.xls` file should include the following columns:
- **Component Name**
- **Type** (3D Model / Modules / IC / Consumables / Sensors & Actuators)
- **Quantity**
- **Part Number** (if applicable)
- **Supplier/Manufacturer/Vendor/Purchased Place**
- **Cost**
- **Description**

---

## 5. Reports and Presentations

Provide your project presentation and reports in either `.pptx`, `.ppt`, or `.pdf` format. This should include a brief overview of your project, objectives, design process, results, and conclusions. This should include all the milestone submission presentations.

### Folder Structure:
```plaintext
/Project-Root
  ├── /reports 
    ├── presentation.pptx # PowerPoint presentation file
    ├── milestone_reports.pdf # Milestone Reports in PDF file
```

## 6. Other Documents

Provide the wiring diagram of your components, attach pictures of your final project on how did you assemble the design. Place these files in the `/others` directory.
Any other important information regarding your project if it doesn't fit into any of the above categories, add it into this subfolder along with a proper README.md file to explain the same.

## Final Notes:
- **Documentation**: Ensure that all your files are well-documented. This includes commenting your code, describing your designs, and providing detailed instructions in your README file.

By following these instructions, your project will be well-organized, easy to understand, and reproducible by others, including professors or staff members who might need to verify or recreate your project in the future.

Thank you, and best of luck with your project!

---

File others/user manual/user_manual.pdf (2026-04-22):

## SACE User Manual

Secure Adaptive Continuum Explorer (SACE) Team TUE-16 — IIT Bombay

## Contents

Introduction | 2
Intended Users | 2
System Overview | 2
Safety Information | 3
Hardware Setup | 3
Software Setup | 4
Operating the Robot | 4
Feedback and System Behavior | 5
Typical Use Workflow | 5
Troubleshooting | 5
Operational Constraints | 5
Shutdown Procedure | 6
Maintenance Guidelines | 6
Additional Resources | 6
Future Improvements | 6
Summary | 6

## Introduction

The Secure Adaptive Continuum Explorer (SACE) is a soft robotic manipulation system designed for navigating constrained environments and performing adaptive grasping using a tendondriven continuum arm. Unlike traditional rigid manipulators, SACE leverages compliant structures to achieve safe interaction and high dexterity.
This manual provides a comprehensive guide for end-users to understand the system setup, operation, and safety protocols. It is structured to ensure that even users with minimal robotics experience can successfully operate the system.
- Set up the system
- Operate the robot using teleoperation
- Understand system feedback and safety mechanisms

## Intended Users

The SACE system is designed for applications that require flexible, adaptive, and safe robotic manipulation in constrained or hard-to-reach environments. Its continuum architecture makes it particularly suitable for domains where traditional rigid manipulators are ineffective.

- Industrial maintenance personnel performing inspection or repair in confined spaces
- Medical and surgical researchers exploring minimally invasive robotic systems
- Search and rescue professionals requiring flexible robotic tools for navigation and object retrieval

The system is especially useful in scenarios demanding high dexterity, compliance, and safe interaction with uncertain environments.
Prerequisites:
- Basic familiarity with Python execution
- Understanding of USB connections and hardware setup
- No prior robotics experience required for basic operation

## System Overview

SACE integrates mechanical, electrical, and software subsystems into a cohesive platform. The continuum arm enables smooth, flexible motion, while the control architecture ensures reliable execution of user commands.
Key Components:
- Continuum robotic arm (4 segments, 10 DOF)
- Tentacle-based soft gripper
- Dual microcontroller system (Master–Slave)
- Laptop-based control interface
- Endoscope camera for visual feedback
- Limit switch safety system

## Safety Information

Safe operation is critical due to the presence of moving mechanical components and electrical systems. Users must follow all precautions to prevent damage to the robot and ensure personal safety.

- Do not exceed bending limits (˜30◦ per segment)
- Ensure all wiring is secure before powering ON
- Keep fingers away from moving tendons and motors
- Use Emergency Stop (SPACE key) in case of abnormal motion
- Always start with the arm in a neutral configuration

## Hardware Setup

Proper hardware setup ensures reliable operation and prevents system failures. The modular design allows straightforward assembly and debugging.
Mechanical Assembly:
- Tentacle → Continuum Links → Base Plate → Lead Screw → Enclosure
- Verify tendon routing and avoid tangling
- Ensure structural rigidity

Electrical Connections:

- Master Pico → Laptop (USB)
- Master ↔ Slave Pico (I2C)
- Motor Drivers → Motors (PWM)
- Encoders → Slave Pico
- Limit Switches → Port Expanders (SPI)

Power Setup:

- Provide 12V input supply
- Ensure 3.3V regulation
- Avoid short between VBUS and 3.3V rail

## Software Setup

The software stack bridges user input and hardware execution. It includes host-side Python scripts and embedded firmware on microcontrollers.
Requirements:

pip install opencv-python pyserial numpy

Steps:

- Flash Master Pico with /src/master code
- Flash Slave Pico with /src/slave code
- Connect devices and identify COM port

Run:

cd src/laptop
python pc_host.py

## Operating the Robot

The system is controlled through an intuitive teleoperation interface combining keyboard and mouse inputs. Motion is guided using a Follow-The-Leader strategy.
Controls:
- Mouse Click – Add trajectory point
- W / S – Extend / retract lead screw
- U / D – Open / close gripper
- R – Undo last motion
- SPACE – Emergency stop
- Q – Quit

Operation Flow:

- Start system and launch control script
- Use camera feed to guide motion
- Input trajectory points
- Perform grasping and retraction

## Feedback and System Behavior

The system continuously monitors safety and performance using sensors and feedback loops. This ensures robust and safe operation even under uncertain conditions.
Feedback Messages:

LIMIT,<mcp_id>,<pin>
TIMEOUT,<motor>,<angle>,<direction>
- LIMIT indicates obstacle or boundary reached
- TIMEOUT indicates unsafe motion duration

Automatic safety mechanisms pause motion and trigger corrective behavior.

## Typical Use Workflow

The following workflow outlines a typical interaction scenario:

- Power ON system
- Run control script
- Locate object via camera
- Define trajectory
- Extend, grasp, and retract

## Troubleshooting

Common issues can often be resolved through systematic checks of hardware and software components.

- Robot not moving: Check USB, COM port, firmware
- Jerky motion: Inspect tendons and spools
- No camera feed: Verify camera connection
- Sudden stops: Check limit switches

## Operational Constraints

The system operates within certain physical and design limitations which must be respected for reliable performance.

- Max bending ∼ 30◦ per link
- Manual teleoperation only
- Backbone hysteresis may occur
- Tendon slack at extreme motion

## Shutdown Procedure

Proper shutdown ensures system longevity and prevents damage.

- Stop motion (SPACE)
- Exit program (Q)
- Disconnect power
- Reset arm

## Maintenance Guidelines

Routine maintenance is essential to sustain performance and reliability.

- Check tendon tension
- Inspect spool wear
- Verify electrical connections
- Recalibrate if needed

## Additional Resources

- Teleoperation: /src/laptop/README.md
- PCB: /pcb/README.md
- CAD Models: /3d models/
- Videos: /others/presentation/video/

## Future Improvements

Potential enhancements include improved autonomy, control precision, and system usability.

- Autonomous navigation
- Improved stability
- Closed-loop control
- Enhanced UI

## Summary

SACE is a modular soft robotic system demonstrating the capabilities of continuum robotics in real-world applications. It combines flexibility, safety, and intuitive control, making it a powerful platform for research and demonstration.

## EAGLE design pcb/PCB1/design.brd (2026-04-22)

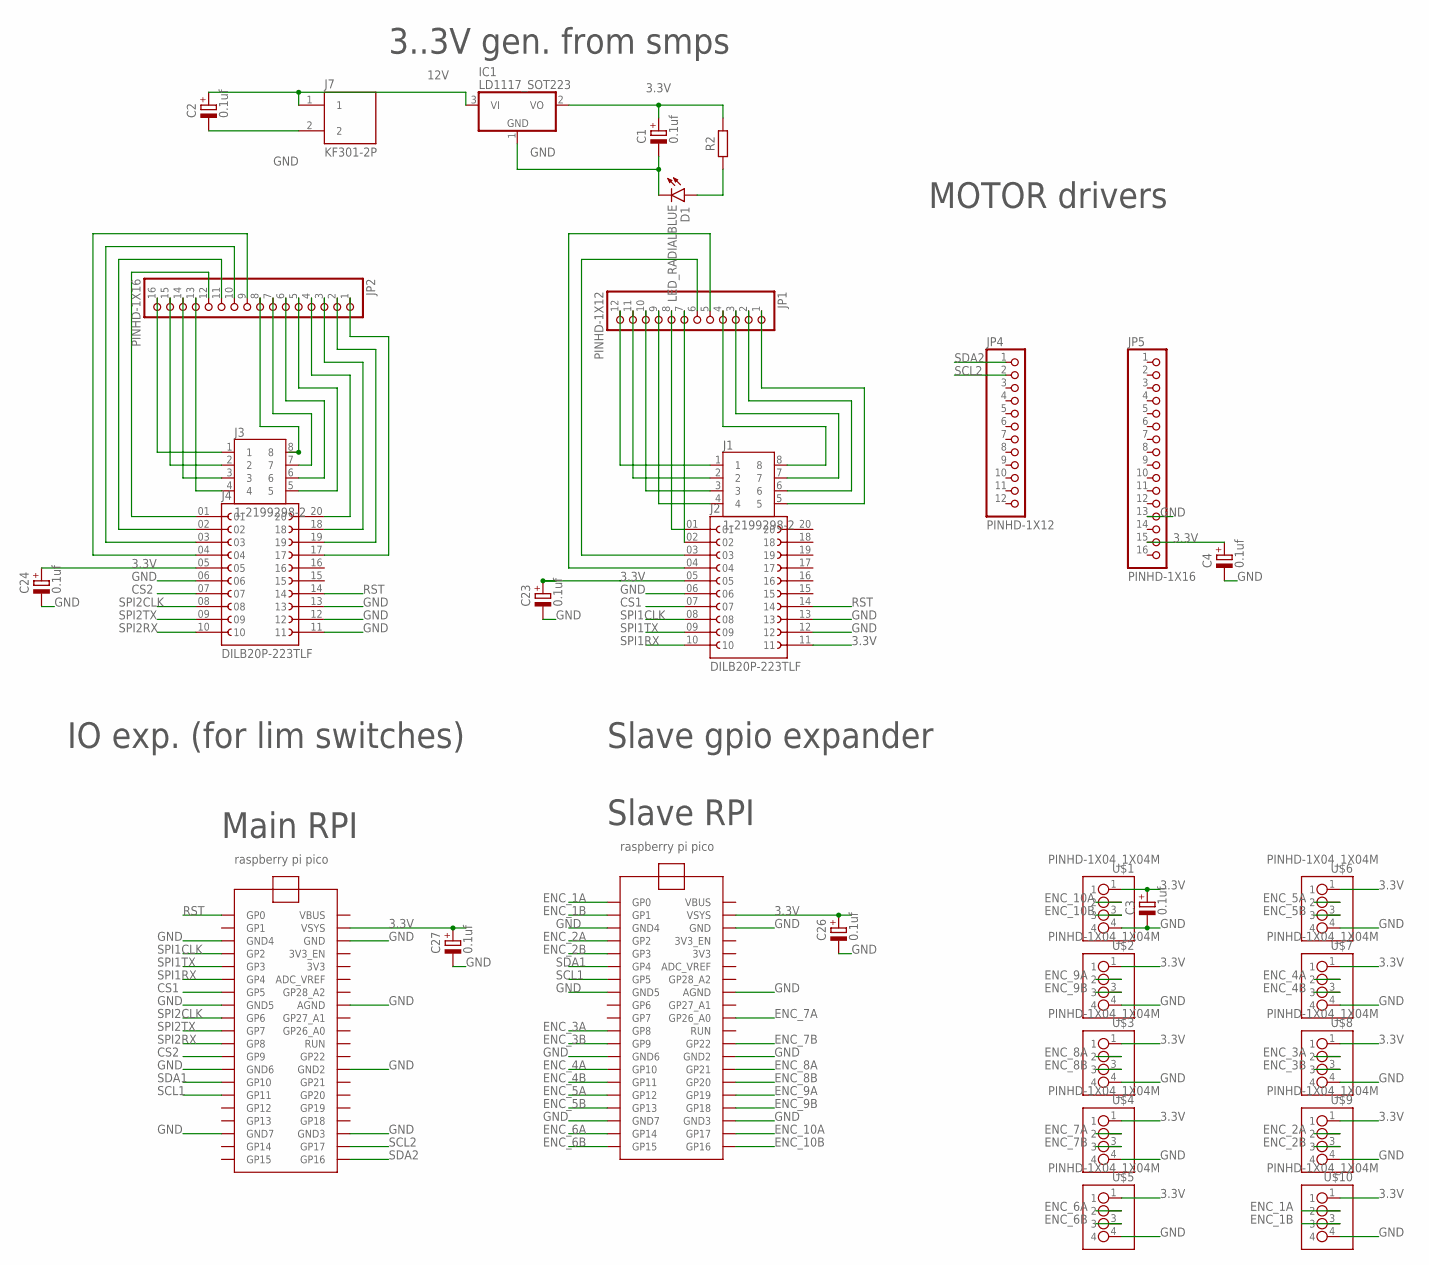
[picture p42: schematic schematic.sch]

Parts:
C1, C2, C3, C4, C23, C24, C26, C27: 0.1uf; CAPPRD254W65D500H1150B
D1: LED_RADIALBLUE; LEDRD254W60D565H860B_B
IC1: LD1117_SOT223; SOT230P700X170-4
J1, J3: 1-2199298-2; TE_1-2199298-2
J2, J4: DILB20P-223TLF; AMPHENOL_DILB20P-223TLF
J7: KF301-2P; HANDSON_KF301-2P
JP1, JP4: PINHD-1X12; 1X12
JP2, JP5: PINHD-1X16; 1X16
R2: R_AXIAL-11.7MM-PITCH; RESAD1176W63L850D250B
U2, U3: RASPBERRY_PI_PICO
U$1, U$2, U$3, U$4, U$5, U$6, U$7, U$8, U$9, U$10: PINHD-1X04_1X04M; 1X04

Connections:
3.3V: C1.1 (+), C3.1 (+), C4.1 (+), C23.1 (+), C24.1 (+), C26.1 (+), C27.1 (+), IC1.2 (VO), J2.05, J2.11, J4.05, JP5.15, R2.2, U2.VSYS, U3.VSYS, U$1.1, U$2.1, U$3.1, U$4.1, U$5.1, U$6.1, U$7.1, U$8.1, U$9.1, U$10.1
12V: C2.1 (+), IC1.3 (VI), J7.1
CS1: J2.07, U2.GP5
CS2: J4.07, U2.GP9
ENC_1A: U3.GP0, U$10.2
ENC_1B: U3.GP1, U$10.3
ENC_2A: U3.GP2, U$9.2
ENC_2B: U3.GP3, U$9.3
ENC_3A: U3.GP8, U$8.2
ENC_3B: U3.GP9, U$8.3
ENC_4A: U3.GP10, U$7.2
ENC_4B: U3.GP11, U$7.3
ENC_5A: U3.GP12, U$6.2
ENC_5B: U3.GP13, U$6.3
ENC_6A: U3.GP14, U$5.2
ENC_6B: U3.GP15, U$5.3
ENC_7A: U3.GP26_A0, U$4.2
ENC_7B: U3.GP22, U$4.3
ENC_8A: U3.GP21, U$3.2
ENC_8B: U3.GP20, U$3.3
ENC_9A: U3.GP19, U$2.2
ENC_9B: U3.GP18, U$2.3
ENC_10A: U3.GP17, U$1.2
ENC_10B: U3.GP16, U$1.3
GND: C1.2 (-), C2.2 (-), C3.2 (-), C4.2 (-), C23.2 (-), C24.2 (-), C26.2 (-), C27.2 (-), D1.C, IC1.1 (GND), J2.06, J2.12, J2.13, J4.06, J4.11, J4.12, J4.13, J7.2, JP5.13, U2.AGND, U2.GND, U2.GND2, U2.GND3, U2.GND4, U2.GND5, U2.GND6, U2.GND7, U3.AGND, U3.GND, U3.GND2, U3.GND3, U3.GND4, U3.GND5, U3.GND6, U3.GND7, U$1.4, U$2.4, U$3.4, U$4.4, U$5.4, U$6.4, U$7.4, U$8.4, U$9.4, U$10.4
GPA1: J3.8, JP2.8
LS1: J1.5, JP1.1
unnamed: D1.A, R2.1
unnamed: J1.1, JP1.12
unnamed: J1.2, JP1.11
unnamed: J1.3, JP1.10
unnamed: J1.4, JP1.9
unnamed: J2.01, JP1.8
unnamed: J1.8, JP1.4
unnamed: J1.7, JP1.3
unnamed: J2.02, JP1.7
unnamed: J2.03, JP1.6
unnamed: J2.04, JP1.5
unnamed: J3.1, JP2.16
unnamed: J3.2, JP2.15
unnamed: J3.3, JP2.14
unnamed: J3.4, JP2.13
unnamed: J4.01, JP2.12
unnamed: J1.6, JP1.2
unnamed: J4.02, JP2.11
unnamed: J4.03, JP2.10
unnamed: J4.04, JP2.9
unnamed: J3.7, JP2.7
unnamed: J3.6, JP2.6
unnamed: J3.5, JP2.5
unnamed: J4.20, JP2.4
unnamed: J4.18, JP2.3
unnamed: J4.19, JP2.2
unnamed: J4.17, JP2.1
RST: J2.14, J4.14, U2.GP0
SCL1: U2.GP11, U3.GP5
SCL2: JP4.2, U2.GP17
SDA1: U2.GP10, U3.GP4
SDA2: JP4.1, U2.GP16
SPI1CLK: J2.08, U2.GP2
SPI1RX: J2.10, U2.GP4
SPI1TX: J2.09, U2.GP3
SPI2CLK: J4.08, U2.GP6
SPI2RX: J4.10, U2.GP8
SPI2TX: J4.09, U2.GP7

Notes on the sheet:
Main RPI
Slave RPI
Slave gpio expander
IO exp. (for lim switches)
MOTOR drivers
3..3V gen. from smps

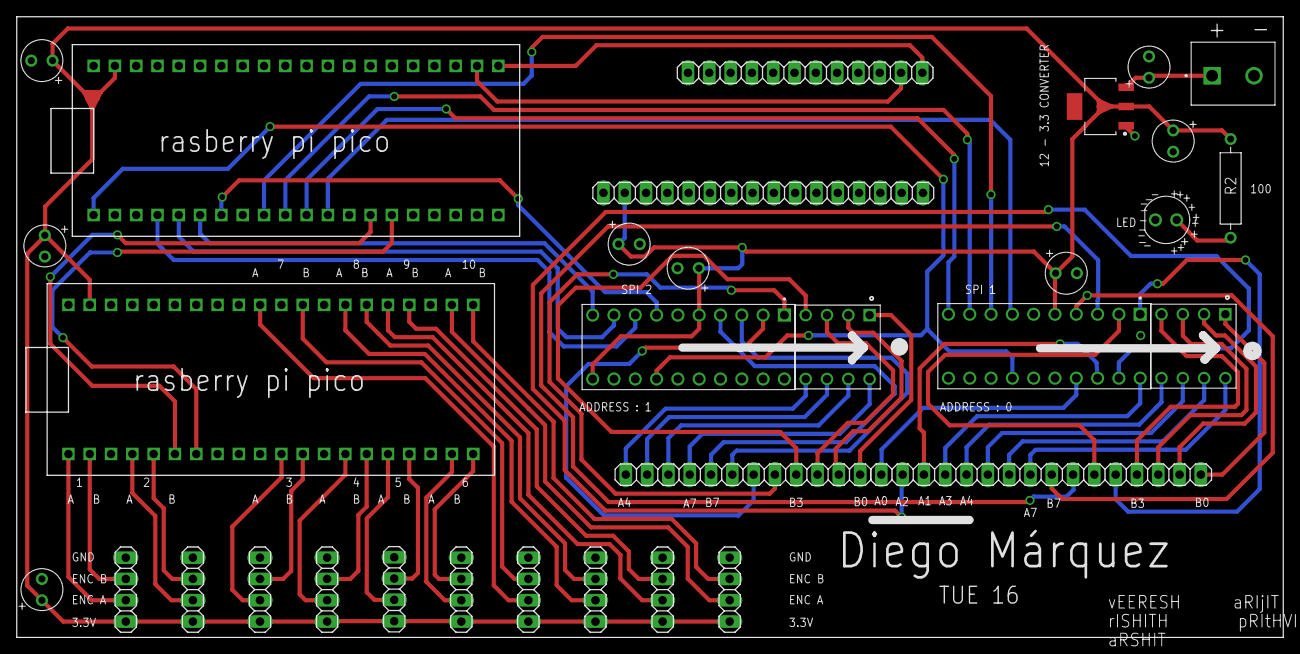
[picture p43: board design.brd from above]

Board: 2 copper layers, 151.0 x 74.0 mm, 32 parts (0 on the bottom side), 65 nets.

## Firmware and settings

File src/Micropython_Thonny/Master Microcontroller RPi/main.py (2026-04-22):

""""
=================================================================================================
This is the driving code of the master RPi. It receives pre-calculated kinematic commands over 
USB Serial from a PC and translates them into physical motor actuations.

Core responsibilities:
1. Serial telemetry       : Listens for serial commands from the PC over the USB cable.
2. Motor Control          : Communicates over I2C with 3 Adafruit FeatherWing Motor Drivers to drive 10 motors using PWM control.
3. Slave communication    : Communicates over I2C with the slave RPi. Constantly polls the Slave for live 
                            telemetry, braking the motor when the target ticks are reached.  
4. Limit Safety Detection : Continuously polls two MCP23S17 port expanders at high speed. If a limit switch is triggered,
                            it halts all motors and broadcasts the triggered pin to the PC for escape route calculation.

Software dependencies:
1. feather_driver.py 
2. mcp23s17.py

Commands:
The following commands are received by the Master RPi over Serial USB, and are used to determine motor movements
1. START,{motor_id},{direction},{angle},{PWM} : Initiates movement for a specific motor in a given direction for a target angle at the defined PWM speed.
2. S                                          : Instantly halts all active motors and clears their current target ticks.
3. GRIP,{direction},{PWM}                     : Controls the tentacle gripper mechanism, setting its actuation direction (0 to engage, 1 to release) 
                                                and tension force via PWM.
=================================================================================================
"""
import machine
import time
import sys
import select
from feather_driver import FeatherDriver
from mcp23s17 import MCP23S17

# For easy visual confirmation that the RPi is ON.
led = machine.Pin("LED", machine.Pin.OUT)
led.value(1)

# ---------------- HARDWARE SETUP ----------------

# Resetting the port expanders
mcp_reset = machine.Pin(0, machine.Pin.OUT)
mcp_reset.value(1)
time.sleep_ms(10)

# These are the port expander pins to which the limit switches are connected
ACTIVE_LIMIT_PINS_1 = list(range(4, 16))                
ACTIVE_LIMIT_PINS_2 = list(range(16))  

# Initializing SPI protocol with the MCP23S17 port expanders
print("Initializing SPI 0 (MCP1)...")
spi = machine.SPI(0, baudrate=1000000, polarity=0, phase=0,
                  sck=machine.Pin(2), mosi=machine.Pin(3), miso=machine.Pin(4))
cs = machine.Pin(5, machine.Pin.OUT)
mcp = MCP23S17(spi, cs)

print("Initializing SPI 1 (MCP2)...")
spi2 = machine.SPI(1, baudrate=1000000, polarity=0, phase=0,
                  sck=machine.Pin(14), mosi=machine.Pin(15), miso=machine.Pin(8))
cs2 = machine.Pin(9, machine.Pin.OUT)
mcp2 = MCP23S17(spi2, cs2)

# Initializing I2C protocol with the slave RPi
print("Initializing I2C Busses...")
i2c_slave = machine.I2C(1, scl=machine.Pin(11), sda=machine.Pin(10), freq=100000)
print(i2c_slave.scan()) #For debugging
SLAVE_ADDR = 0x50

# Initializing I2C protocol with the FeatherWing Motor drivers
i2c_motor = machine.I2C(0, scl=machine.Pin(17), sda=machine.Pin(16), freq=100000)
print(i2c_motor.scan())
feathers = FeatherDriver(i2c_motor, addresses=[0x60,0x61,0x62]) # 3 addressed for 3 featherwings, each FeatherWing can control upto 4 motors

# Serial communication over USB with the PC
usb_poll = select.poll()
usb_poll.register(sys.stdin, select.POLLIN)

# Parameters
NUM_ENCODERS = 8 
NUM_MOTORS = 10   
move_in_progress = [False] * NUM_MOTORS
current_directions = [True] * NUM_MOTORS
current_targets = [0] * NUM_MOTORS
move_start_times = [0] * NUM_MOTORS 

# --- EDGE DETECTION TRACKERS ---
prev_limit_state_1 = 0xFFFF # for the first port expander
prev_limit_state_2 = 0xFFFF # for the second port expander

# Brake all the motors at power-up.
print("MASTER READY. Initializing braking sequence...")
for m in range(NUM_MOTORS):
    feathers.state_hold(m)
print("[SYSTEM] All 10 motors locked in HOLD state.")

while True:
    # ==========================================
    # TASK 0: LIMIT SWITCH EDGE DETECTION
    # ==========================================
    try:
        # Read all the limit switch pins
        limit_state_1 = mcp.read_all()
        limit_state_2 = mcp2.read_all()
        
        triggered_mcp = -1
        triggered_pin = -1
        
        # Check first port expander for a fresh press (HIGH now, but was LOW previously)
        for pin in ACTIVE_LIMIT_PINS_1:
            if (limit_state_1 & (1 << pin)) != 0 and (prev_limit_state_1 & (1 << pin)) == 0:
                triggered_mcp = 1
                triggered_pin = pin
                break 
                
        # Check MCP2 for a fresh press
        if triggered_mcp == -1:
            for pin in ACTIVE_LIMIT_PINS_2:
                if (limit_state_2 & (1 << pin)) != 0 and (prev_limit_state_2 & (1 << pin)) == 0:
                    triggered_mcp = 2
                    triggered_pin = pin
                    break
                  
        # If a limit switch was triggered, then halt all active motors
        if triggered_mcp != -1:
            any_motor_stopped = False
            feathers.state_hold(8) 
            feathers.state_hold(9) 

            # Stop active motors
            for m in range(NUM_ENCODERS):
                if move_in_progress[m]:
                    feathers.state_hold(m)
                    move_in_progress[m] = False
                    any_motor_stopped = True
                    
            if move_in_progress[9]:
                move_in_progress[9] = False
                any_motor_stopped = True

            # Alert the PC that a limit switch was triggered.
            print(f"LIMIT,{triggered_mcp},{triggered_pin}")
            
        # Update states for the next loop
        prev_limit_state_1 = limit_state_1
        prev_limit_state_2 = limit_state_2
            
    except Exception as e:
        pass
        
    # ==========================================
    # TASK 1: USB / PC COMMANDS
    # ==========================================
    if usb_poll.poll(0):
        command = sys.stdin.readline().strip().upper()

        if command == "S": # Stop all motors
            for m in range(NUM_MOTORS):
                feathers.state_hold(m)
                move_in_progress[m] = False
                current_targets[m] = 0
            print("[SYSTEM] EMERGENCY STOP. All motors braked.")
            
        elif command.startswith("GRIP"): # Grip the tentacle
            parts = command.split(',')
            state = int(parts[1])
            pwm_percent = int(parts[2])
            if state == 1:
                feathers.state_move(8, forward=True, speed=pwm_percent)
            else:
                feathers.state_move(8, forward=False, speed=pwm_percent)
            
        elif command.startswith("START"): # Initialize the motor PWM control
            parts = command.split(',')
            if len(parts) == 5:
                motor_id = int(parts[1])
                direction = int(parts[2])
                angle = int(parts[3]) 
                pwm_percent = int(parts[4])

                if motor_id == 9: # Lead screw motion
                    if pwm_percent == 0:
                        feathers.state_hold(9)
                        move_in_progress[9] = False
                    else:
                        fwd = bool(direction)
                        feathers.state_move(9, forward=fwd, speed=pwm_percent)
                        move_in_progress[9] = True
                        move_start_times[9] = time.ticks_ms()

                elif 0 <= motor_id < NUM_ENCODERS: # Continuum link motion
                    if not move_in_progress[motor_id]:
                        fwd = bool(direction)
                        current_directions[motor_id] = fwd
                        
                        target_ticks = int((angle / 360.0) * 1035) # 1035 encoder ticks corresponds to one full rotation of motor shaft
                        brake_target = target_ticks 
                        current_targets[motor_id] = brake_target
                        
                        try: i2c_slave.writeto(SLAVE_ADDR, bytearray([0x01, motor_id])) # Tell the slave RPi to reset the encoder ticks to 0 for that motor
                        except: pass

                        # Wait for slave RPi to reset encoder ticks of that motor to 0.
                        reset_confirmed = False
                        for _ in range(50): 
                            try:
                                check_data = i2c_slave.readfrom(SLAVE_ADDR, 16)
                                check_ticks = int.from_bytes(check_data[(motor_id*2) : 2 + (motor_id*2)], 'little')
                                if check_ticks == 0:
                                    reset_confirmed = True
                                    break
                            except: pass
                            time.sleep_ms(1)
                            
                        if not reset_confirmed:
                            print(f"Slave has failed to reset encoder ticks of motor {motor_id}") # Debug statement
                            continue

                        # Start the motor
                        feathers.state_move(motor_id, forward=fwd, speed=pwm_percent)
                        move_in_progress[motor_id] = True
                        move_start_times[motor_id] = time.ticks_ms() 

    # ==========================================
    # TASK 2: LIVE TELEMETRY & TIMEOUT CHECK
    # ==========================================
    if any(move_in_progress):
        try:
            data = i2c_slave.readfrom(SLAVE_ADDR, 16) # Request encoder values of all 8 motors from slave.

            # Iterate through all link motors to check their live telemetry
for m in range(NUM_ENCODERS):
    
    # Only process motors that are currently flagged as moving
    if move_in_progress[m]:
        
        # Extract the 16-bit encoder tick count from the I2C byte array (Little Endian)
        # Each motor gets 2 bytes, so motor 'm' is located at index [m*2] and [m*2 + 1]
        live_ticks = int.from_bytes(data[(m*2) : 2 + (m*2)], 'little')
        
        # --- CONDITION 1: SUCCESSFUL MOVE ---
        # The motor has reached or slightly overshot its target tick count
        if live_ticks >= current_targets[m]:
            feathers.state_hold(m)           # Instantly brake the motor
            move_in_progress[m] = False      # Clear the moving flag
            current_targets[m] = 0           # Reset the target
            print(f"[SYSTEM] M{m} Reached Target.")
        
        # --- CONDITION 2: SAFETY TIMEOUT ---
        # If 2000ms (2 seconds) pass before reaching the target, assume it's jammed
        elif time.ticks_diff(time.ticks_ms(), move_start_times[m]) > 2000:
            feathers.state_hold(m)           # Brake to prevent motor burnout
            move_in_progress[m] = False
            current_targets[m] = 0
            
            # Calculate exactly how far it DID move before jamming (1035 ticks = 360 deg)
            actual_deg = int((live_ticks / 1035.0) * 360)
            
            # Broadcast the exact stall position back to the PC Controller
            print(f"TIMEOUT,{m},{actual_deg},{int(current_directions[m])}")

        except Exception as e:
            pass

        # Lead screw motor does not have any encoder. It automatically times out after 2 seconds.
        if move_in_progress[9]:
            if time.ticks_diff(time.ticks_ms(), move_start_times[9]) > 2000:
                feathers.state_hold(9)
                move_in_progress[9] = False
                print("[SYSTEM] M9 Lead Screw 2s TIMEOUT - Halted.")

    time.sleep_ms(2)

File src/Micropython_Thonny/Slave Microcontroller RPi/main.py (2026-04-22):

"""
=====================================================================================
This script configures the slave RPi Pico to act as a dedicated, 
high-speed hardware encoder coprocessor. It operating strictly as an I2C Peripheral to the master RPi. 
It handles the computationally expensive task of tracking thousands of motor pulses per second across 8 DC motors.

Instead of relying on standard CPU interrupts (which can drop ticks at high speeds),
we leverage the RP2040's PIO state machines. 
The PIO blocks count quadrature encoder pulses in the background with zero CPU overhead. 

Core Responsibilities:
1. High-Speed Pulse Counting : Manages 8 PIO state machines to track link motors.
2. Target Zeroing            : Listens for command from the Master to instantly 
                               reset a specific encoder's tick count to 0 before a move.
3. Telemetry Streaming       : Packages all 8 encoder counts into a continuous 16-byte 
                               Little-Endian payload upon Master request.

Software Dependencies:
1. i2c_responder.py 
=====================================================================================
"""

import rp2
import machine
import time
from i2c_responder import I2CResponder 

# For convenient visual confirmation that the slave is ON, we turn on the LED.
led = machine.Pin("LED", machine.Pin.OUT)
led.value(1)

# ==========================================
# 1. PIO ENCODER CLASS (For the 8 Links)
# ==========================================
# This assembly runs directly on the PIO hardware block, not the main CPU.
# It waits for Pin A to change, reads both A and B, and pushes the binary 
# state into a hardware queue (RX FIFO) for the Python CPU to evaluate later.
@rp2.asm_pio()
def quadrature_encoder():
    wrap_target()
    wait(1, pin, 0)      # Block and wait for Pin A to go HIGH
    in_(pins, 2)         # Read the state of Pin A and Pin B (2 bits)
    push(noblock)        # Push that 2-bit state into the hardware FIFO
    wait(0, pin, 0)      # Block and wait for Pin A to go LOW
    wrap()

class PIOEncoder:
    def __init__(self, sm_id, pin_a, pin_b):
        # Bind the assembly code to a specific State Machine and GPIO pair
        self.sm = rp2.StateMachine(sm_id, quadrature_encoder, in_base=pin_a)
        self.pin_a = pin_a
        self.pin_b = pin_b
        self.ticks = 0
        self.sm.active(1) # Start the hardware state machine

    def read(self):
        # Drain the hardware queue. Evaluate the 2-bit state to determine direction.
        while self.sm.rx_fifo():
            state = self.sm.get() & 0x03 # State is either 01 or 11
            
            # Quadrature Logic: If A leads B, it's state 1. If B leads A, it's state 3.
            if state == 1:       
                self.ticks += 1  # Forward tick
            elif state == 3:     
                self.ticks -= 1  # Backward tick
                
        return abs(self.ticks) # PC Controller only cares about absolute distance traveled
        
    def reset(self):
        # Clear any leftover data in the queue and zero out the counter
        while self.sm.rx_fifo():
            self.sm.get()
        self.ticks = 0

# ==========================================
# 2. SYSTEM SETUP
# ==========================================
NUM_MOTORS = 8 # Tracking the 8 Continuum Links

print("Initializing Encoders (8 PIO)...")
# Map the 8 State Machines to their physical GPIO pin pairs
encoders = [
    PIOEncoder(0, machine.Pin(0), machine.Pin(1)),
    PIOEncoder(1, machine.Pin(2), machine.Pin(3)),
    PIOEncoder(2, machine.Pin(8), machine.Pin(9)),
    PIOEncoder(3, machine.Pin(10), machine.Pin(11)),
    PIOEncoder(4, machine.Pin(12), machine.Pin(13)),
    PIOEncoder(5, machine.Pin(14), machine.Pin(15)),
    PIOEncoder(6, machine.Pin(22), machine.Pin(26)),
    PIOEncoder(7, machine.Pin(20), machine.Pin(21))
]

# Initialize the RPi Pico as an I2C Peripheral (Slave) on Address 0x50
i2c_target = I2CResponder(i2c_device_id=0, sda_gpio=4, scl_gpio=5, responder_address=0x50)
print("SLAVE READY. Tracking 8 Encoders.")

incoming_buffer = []

while True:
    # --- TASK 1. DRAIN FIFOS / UPDATE TICKS ---
    # The PIO hardware is counting infinitely fast. We just empty the queue 
    # every loop to update our Python variable.
    for m in range(NUM_MOTORS):
        encoders[m].read()

    # --- TASK 2. HANDLE MASTER COMMANDS (WRITES) ---
    # If the Master Pico sends data, we parse it. 
    # Expected format: [Command_Byte, Motor_ID_Byte]
    if i2c_target.write_data_is_available():
        incoming_buffer.extend(i2c_target.get_write_data(max_size=2))
        
    if len(incoming_buffer) >= 2:
        cmd = incoming_buffer[0]
        m = incoming_buffer[1]
        
        # 0x01 is the "reset encoder" command.
        if cmd == 0x01 and 0 <= m < NUM_MOTORS:
            encoders[m].reset() # sets encoder ticks to 0, to start counting from 0
            
        incoming_buffer = incoming_buffer[2:] # Clear processed bytes from buffer

    # --- TASK 3. SEND TELEMETRY PACKET (READS) ---
    # If the Master Pico requests data, we package all 8 encoders into 16 bytes
    if i2c_target.read_is_pending():
        data_packet = bytearray(16) # 8 motors * 2 bytes each = 16 bytes
        
        for m in range(NUM_MOTORS):
            current_ticks = abs(encoders[m].ticks)
            
            # Little-Endian Formatting: 
            # Slice the 16-bit integer into two 8-bit bytes for I2C transmission
            data_packet[(m*2)] = current_ticks & 0xFF        # Low Byte
            data_packet[1 + (m*2)] = (current_ticks >> 8) & 0xFF  # High Byte
            
        # Push the bytes into the hardware output buffer for the Master to clock out
        for byte in data_packet:
            i2c_target.put_read_data(byte)

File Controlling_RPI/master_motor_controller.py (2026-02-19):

"""
Motor Control System for Robotic Arm
Handles communication with slave devices for motor control
"""

import time
import math
import threading
from enum import Enum
from master_config import *


class MotorDirection(Enum):
    """Motor rotation directions"""
    FORWARD = 1
    REVERSE = 0
    STOP = 2


class MotorController:
    """
    Main motor controller for 8 motors:
    - Motors 0-1: Tentacle end effector
    - Motors 2-7: Continuum robot joints
    """

    def __init__(self, pwm_address=PWM_GENERATOR_ADDRESS, gpio_expander_1_address=GPIO_EXPANDER_1_ADDRESS,
                 gpio_expander_2_address=GPIO_EXPANDER_2_ADDRESS, slave_rpi_address=SLAVE_RPI_ADDRESS):
        """
        Initialize motor controller with slave addresses

        Args:
            pwm_address: I2C address of PWM generator
            gpio_expander_1_address: I2C address of GPIO expander for motor directions
            gpio_expander_2_address: I2C address of GPIO expander for limit switches
            slave_rpi_address: I2C address of slave RPi for encoder readings
        """
        self.pwm_address = pwm_address
        self.gpio_expander_1_address = gpio_expander_1_address
        self.gpio_expander_2_address = gpio_expander_2_address
        self.slave_rpi_address = slave_rpi_address

        # Motor states
        self.motor_speeds = [0] * NUM_MOTORS  # PWM duty cycles (0-PWM_MAX_VALUE)
        self.motor_directions = [MotorDirection.STOP] * NUM_MOTORS

        # Encoder values from slave RPi
        self.encoder_values = [0] * NUM_MOTORS

        # Limit switch states
        self.limit_switches = [False] * NUM_LIMIT_SWITCHES

        # Control thread
        self.control_thread = None
        self.running = False

        # Initialize I2C bus (placeholder - will be implemented with actual hardware)
        self.i2c_bus = None

    def initialize_hardware(self):
        """Initialize I2C communication and slave devices"""
        try:
            # Import smbus for I2C communication (Raspberry Pi)
            import smbus
            self.i2c_bus = smbus.SMBus(1)  # I2C bus 1 on RPi

            # Initialize PWM generator (PCA9685)
            self._init_pwm_generator()

            # Initialize GPIO expanders (MCP23017)
            self._init_gpio_expanders()

            print("[MotorController] Hardware initialized successfully")
            return True

        except ImportError:
            print("[MotorController] Warning: smbus not available (simulation mode)")
            return False
        except Exception as e:
            print(f"[MotorController] Hardware initialization failed: {e}")
            return False

    def _init_pwm_generator(self):
        """Initialize PCA9685 PWM generator"""
        if self.i2c_bus:
            # Set PWM frequency to configured value
            self.i2c_bus.write_byte_data(self.pwm_address, 0x00, 0x10)  # MODE1 register
            time.sleep(0.01)
            # Set frequency
            prescale = int(25000000 / (4096 * PWM_FREQUENCY) - 1)
            self.i2c_bus.write_byte_data(self.pwm_address, 0xFE, prescale)  # PRE_SCALE register
            time.sleep(0.01)
            self.i2c_bus.write_byte_data(self.pwm_address, 0x00, 0x00)  # MODE1 register

    def _init_gpio_expanders(self):
        """Initialize MCP23017 GPIO expanders"""
        if self.i2c_bus:
            # GPIO Expander 1: Motor directions (8 outputs)
            self.i2c_bus.write_byte_data(self.gpio_expander_1_address, 0x00, 0x00)  # IODIRA - all outputs
            self.i2c_bus.write_byte_data(self.gpio_expander_1_address, 0x01, 0x00)  # IODIRB - all outputs

            # GPIO Expander 2: Limit switches (16 inputs)
            self.i2c_bus.write_byte_data(self.gpio_expander_2_address, 0x00, 0xFF)  # IODIRA - all inputs
            self.i2c_bus.write_byte_data(self.gpio_expander_2_address, 0x01, 0xFF)  # IODIRB - all inputs

    def set_motor_speed(self, motor_id, speed, direction):
        """
        Set speed and direction for a specific motor

        Args:
            motor_id (int): Motor ID (0-7)
            speed (float): Speed (0.0 to 1.0)
            direction (MotorDirection): Motor direction
        """
        if not 0 <= motor_id < NUM_MOTORS:
            print(f"[MotorController] Invalid motor ID: {motor_id}")
            return

        # Convert speed to PWM duty cycle (0-PWM_MAX_VALUE)
        pwm_value = int(speed * PWM_MAX_VALUE)

        self.motor_speeds[motor_id] = pwm_value
        self.motor_directions[motor_id] = direction

        # Send to hardware
        self._update_motor_hardware(motor_id)

    def _update_motor_hardware(self, motor_id):
        """Update motor control hardware"""
        if self.i2c_bus:
            # Set PWM duty cycle
            pwm_reg = 0x06 + motor_id * 4  # LED0_ON_L + motor_id * 4
            on_value = 0
            off_value = self.motor_speeds[motor_id]

            self.i2c_bus.write_byte_data(self.pwm_address, pwm_reg, on_value & 0xFF)
            self.i2c_bus.write_byte_data(self.pwm_address, pwm_reg + 1, on_value >> 8)
            self.i2c_bus.write_byte_data(self.pwm_address, pwm_reg + 2, off_value & 0xFF)
            self.i2c_bus.write_byte_data(self.pwm_address, pwm_reg + 3, off_value >> 8)

            # Set direction via GPIO expander
            current_directions = 0
            for i in range(8):
                if self.motor_directions[i] == MotorDirection.FORWARD:
                    current_directions |= (1 << i)

            self.i2c_bus.write_byte_data(self.gpio_expander_1_address, 0x12, current_directions & 0xFF)  # GPIOA
            self.i2c_bus.write_byte_data(self.gpio_expander_1_address, 0x13, current_directions >> 8)   # GPIOB

    def read_encoders(self):
        """Read encoder values from slave RPi"""
        if self.i2c_bus:
            try:
                # Read 16 bytes (2 bytes per encoder * 8 encoders)
                data = []
                for i in range(16):
                    data.append(self.i2c_bus.read_byte_data(self.slave_rpi_address, i))

                # Convert to 16-bit values
                for i in range(8):
                    self.encoder_values[i] = (data[i*2] << 8) | data[i*2 + 1]

            except Exception as e:
                print(f"[MotorController] Encoder read failed: {e}")

        return self.encoder_values.copy()

    def read_limit_switches(self):
        """Read limit switch states from GPIO expander 2"""
        if self.i2c_bus:
            try:
                gpioa = self.i2c_bus.read_byte_data(self.gpio_expander_2_address, 0x12)
                gpiob = self.i2c_bus.read_byte_data(self.gpio_expander_2_address, 0x13)

                switches = (gpiob << 8) | gpioa
                for i in range(16):
                    self.limit_switches[i] = bool(switches & (1 << i))

            except Exception as e:
                print(f"[MotorController] Limit switch read failed: {e}")

        return self.limit_switches.copy()
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

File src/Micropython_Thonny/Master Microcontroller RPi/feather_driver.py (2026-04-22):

"""
=====================================================================================
This module acts as the Hardware Abstraction Layer (HAL) for the physical DC motors. 
It interfaces with a daisy-chained array of Adafruit Motor Shields (PCA9685 chips) 
over a single I2C bus to drive the tendon-actuation and lead screw mechanisms.

Core Responsibilities:
1. Flat-Index Mapping        : Abstracts multiple physical I2C boards into a single, 
                               continuous array, so the Master script doesn't have to calculate board addresses.
2. PWM Scaling               : Translates speed percentages (0-100%) into 12-bit hardware duty cycles (0-4095).


Software Dependencies:
1. pca9685.py (Standard MicroPython PCA9685 driver library)
=====================================================================================
"""

from pca9685 import PCA9685

class FeatherDriver:
    # Pin mappings for the Adafruit Motor Shield V2 / FeatherWing
    # Format: (PWM_Pin, IN1_Pin, IN2_Pin)
    MOTOR_PINS = [
        (8, 10, 9),   # Motor 1 (M1 on board)
        (13, 11, 12), # Motor 2 (M2 on board)
        (2, 4, 3),    # Motor 3 (M3 on board)
        (7, 5, 6)     # Motor 4 (M4 on board)
    ]

    def __init__(self, i2c_bus, addresses=[0x60, 0x61, 0x62]):
        self.boards = []
        # Initialize each PCA9685 board found in the address list
        for addr in addresses:
            board = PCA9685(i2c_bus, address=addr)
            board.freq(1600)  # Standard PWM frequency for DC motors
            self.boards.append(board)
            
        self.PWM_MAX = 4095
        self.PWM_TENSION = 800   # Low holding voltage to keep tendons tight
        self.PWM_HOLD = 0        

    def set_motor(self, global_motor_index, speed, direction_forward=True):
        # Calculate which physical board and which local motor port to use
        board_idx = global_motor_index // 4
        local_motor_idx = global_motor_index % 4
        
        if board_idx >= len(self.boards):
            return 
            
        board = self.boards[board_idx]
        pwm_pin, in1_pin, in2_pin = self.MOTOR_PINS[local_motor_idx]
        
        board.duty(pwm_pin, speed)
        
        if speed == 0:
            # Both pins must be 4095 (HIGH) to lock the shaft
            board.duty(in1_pin, 4095)
            board.duty(in2_pin, 4095)
        elif direction_forward:
            board.duty(in1_pin, 4095) 
            board.duty(in2_pin, 0)    
        else:
            board.duty(in1_pin, 0)    
            board.duty(in2_pin, 4095) 

    def state_move(self, motor_index, forward=True, speed=100):
        # High-level command to move a motor using 0-100% speed scaling.
        clamped_speed = max(0, min(100, speed))
        pwm_value = int((clamped_speed / 100.0) * 4095)
        self.set_motor(motor_index, pwm_value, forward)

    def state_tension(self, motor_index, forward=True):
        #Applies a low holding voltage to spool up slack cable.
        self.set_motor(motor_index, self.PWM_TENSION, forward)

    def state_hold(self, motor_index, forward=True):
        #Instantly halts and locks the motor shaft.
        self.set_motor(motor_index, self.PWM_HOLD, forward)

    def set_grasp(self, is_grasping):
        #Dedicated helper function for the Gripper actuator (Motor 8).
        self.set_motor(8, self.PWM_MAX if is_grasping else 0, True)

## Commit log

2026-02-27 Updated Code for implemented limit switches and up,down movement
    [Gantt_chart_AUTO_colored_v2.xlsx]
2026-03-03 Everything in UART now
2026-03-06 Limit switch incorporated
2026-04-22 Updated Repo
    [Base plate_it 2.stl, Base_Link.stl, Gantt_chart_AUTO_colored_v2.xlsx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]
